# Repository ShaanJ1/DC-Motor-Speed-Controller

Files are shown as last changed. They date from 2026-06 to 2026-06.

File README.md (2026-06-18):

# DC-Motor-Speed-Controller
A PWM speed controller made for the 775 DC Motor, but can be used with other motors as well. It features on/off buttons, an indicator LED, and a potentiometer to control the motor's speed

I made this as Version 2 of my motor controller for my V8 Engine project, as that board failed to work entirely because of bad design.

# Bill of Materials (BOM)

| **Item Name/Purpose** | **Product Number** | **URL** | **Price** | **Quantity** | **Designator** | **Note** |
| --- | --- | --- | ---: | ---: | --- | --- |
| PCB | | https://jlcpcb.com/ | $3.50 | 5 | | |
| P Channel MOSFET | SI2323CDS-T1-BE3 | https://www.digikey.com/en/products/detail/vishay-siliconix/SI2323CDS-T1-BE3/16397482 | $1.21 | 1 | Q4 | |
| Zener Diode | MMSZ5V6T1G | https://www.digikey.ca/en/products/detail/onsemi/MMSZ5V6T1G/1749053 | $0.17 | 1 | D1 | |
| NPN Transistor | MMBT2222A-TP | https://www.digikey.ca/en/products/detail/mcc-micro-commercial-components/MMBT2222A-TP/717279 | $0.24 | 2 | Q3, Q6 | |
| 6A 2920 PTC Fuse | 2920L600/16MR | https://www.digikey.ca/en/products/detail/littelfuse-inc/2920L600-16MR/14320022 | $2.20 | 2 | F1 | |
| Flywheeling Diode | MBR2045CT | https://www.digikey.ca/en/products/detail/taiwan-semiconductor-corporation/MBR2045CT/7357796 | $1.72 | 1 | D3 | |
| N Channel MOSFET | IRF3205STRLPBF | https://www.digikey.ca/en/products/detail/infineon-technologies/IRF3205STRLPBF/856540 | $3.00 | 1 | Q5 | |
| Diode | 1N4148W-13-F | https://www.digikey.ca/en/products/detail/diodes-incorporated/1N4148W-13-F/1933928 | $0.36 | 2 | D5, D6 | |
| 0.01uF 0603 Capacitor | 06035C103MAZ2A | https://www.digikey.ca/en/products/detail/kyocera-avx/06035C103MAZ2A/11250083 | $0.12 | 1 | C2 | |
| 0.1uF 0704 C0G/NP0 Capacitor | GRMJN65C1H104JE01D | https://www.digikey.ca/en/products/detail/murata-electronics/GRMJN65C1H104JE01D/19115560 | $0.37 | 1 | C1 | |
| 555 Timer | LMC555 | https://www.digikey.ca/en/products/detail/texas-instruments/LMC555CMX-NOPB/334874 | $1.15 | 1 | U1 | |
| 10k 0603 Resistor | RC0603FR-0710KL | https://www.digikey.ca/en/products/detail/yageo/RC0603FR-0710KL/726880 | $0.25 | 10 | R1, R5, R6, R8, R11 | Cheaper to get 10 resistors than only 5 |
| 4.7K 0603 Resistor | RMCF0603FT4K70 | https://www.digikey.ca/en/products/detail/stackpole-electronics-inc/RMCF0603FT4K70/1760998 | $0.10 | 1 | R2 | |
| 1K 0603 Resistor | RMCF0603FT1K00 | https://www.digikey.ca/en/products/detail/stackpole-electronics-inc/RMCF0603FT1K00/1761077 | $0.21 | 10 | R3, R4, R7, R9, R10 | Cheaper to get 10 resistors than only 5 |
| 0805 SMD LED | LTST-C171KGKT | https://www.digikey.ca/en/products/detail/liteon/LTST-C171KGKT/386799 | $0.12 | 1 | D4 | |
| 1x2 Screw Terminals | 282837-2 | https://www.digikey.ca/en/products/detail/te-connectivity-amp-connectors/282837-2/2187973 | $3.44 | 2 | J1, M1 | |

#### <ins>Totals (not including taxes or shipping)</ins>

**Total (CAD):** $17.72

**Total (USD):** $12.57

### Images
Schematic


PCB




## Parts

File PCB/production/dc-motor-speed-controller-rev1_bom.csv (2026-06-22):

Designator | Footprint | Quantity | Value | LCSC Part #
C1 | GRMJN65C1H104JE01D | 1 | 100nF
C2 | 0603 | 1 | 0.01uF
D1 | D_SOD-123 | 1 | D_Zener
D3 | TO-220-3_Horizontal_TabDown | 1 | D
D4 | 0805 | 1 | LED
D5, D6 | Nexperia_CFP3_SOD-123W | 2 | D
F1 | 2920 | 1 | Fuse
J1 | TerminalBlock_Phoenix_MKDS-1,5-2-5.08_1x02_P5.08mm_Horizontal | 1 | Screw_Terminal_01x02
J10, J2, J3, J4, J5, J6, J7, J8, J9 | TestPoint_THTPad_2.0x2.0mm_Drill1.0mm | 9 | Conn_01x01
M1 | TerminalBlock_Phoenix_MKDS-1,5-2-5.08_1x02_P5.08mm_Horizontal | 1 | Motor_DC
Q2 | SOT-23 | 1 | NMOS
Q3, Q6 | SOT-23 | 2 | MMBT2222A
Q4 | SOT-23 | 1 | Si2319CDS
Q5 | TO-263-2 | 1 | NMOS
R1, R11, R5, R6, R8 | 0603 | 5 | 10K
R10, R3, R4, R7, R9 | 0603 | 5 | 1K
R2 | 0603 | 1 | 4.7K
U1 | SOIC-8_3.9x4.9mm_P1.27mm | 1 | LMC555xM

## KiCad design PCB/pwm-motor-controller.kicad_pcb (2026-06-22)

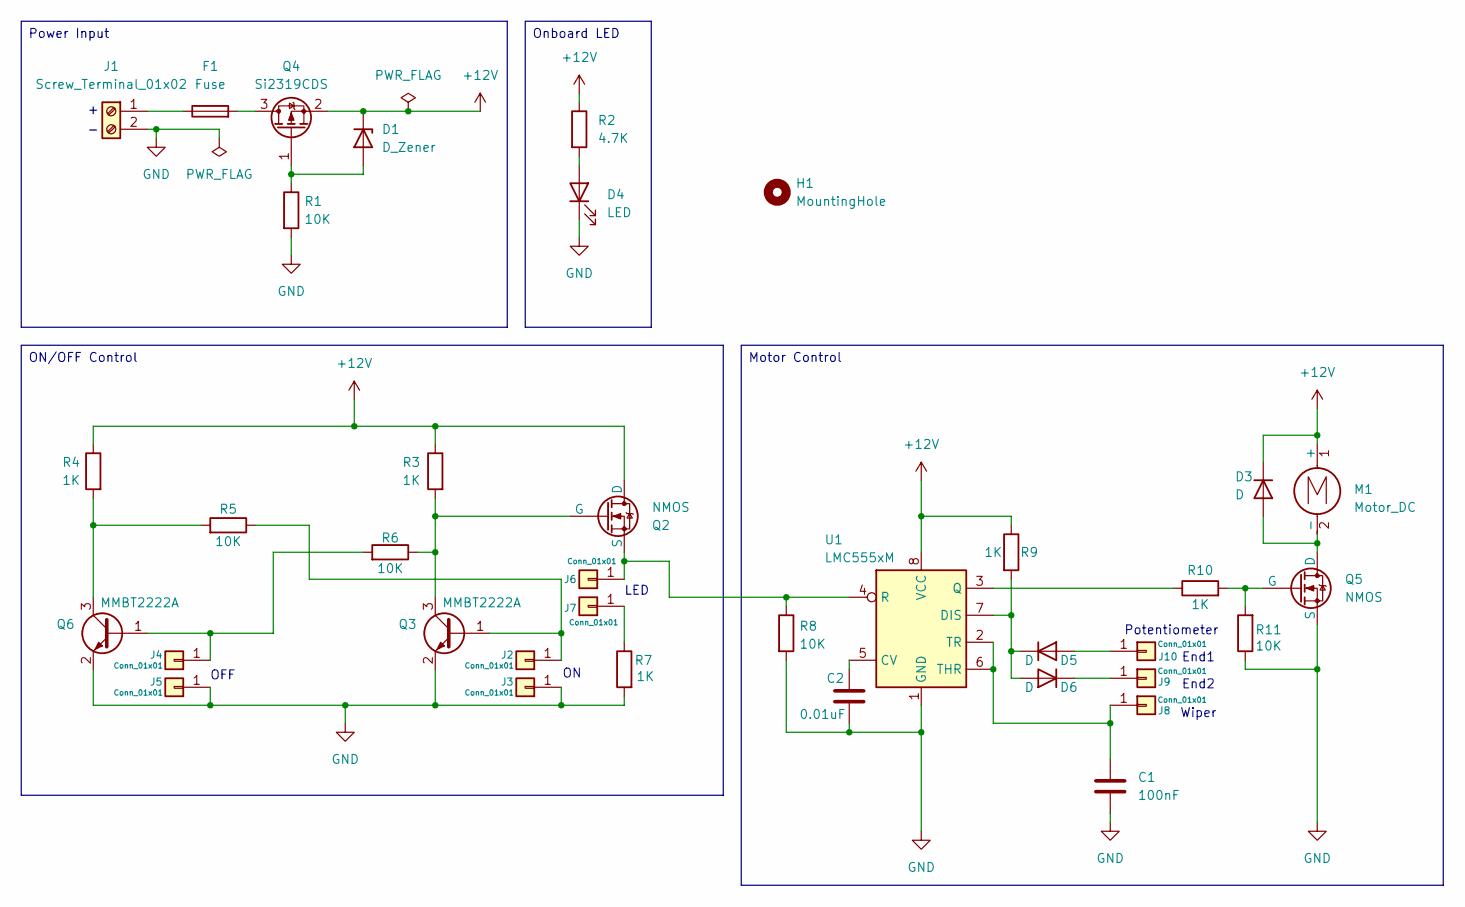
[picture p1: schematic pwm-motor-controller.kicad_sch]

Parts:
C1: 100nF; GRMJN65C1H104JE01D
C2: 0.01uF; C_0603_1608Metric
D1: D_Zener; D_SOD-123
D3: D; TO-220-3_Horizontal_TabDown
D4: LED; LED_0805_2012Metric_Pad1.15x1.40mm_HandSolder
D5, D6: D; Nexperia_CFP3_SOD-123W
F1: Fuse; Fuse_2920_7451Metric
H1: MountingHole; MountingHole_2.7mm_M2.5
J1: Screw_Terminal_01x02; TerminalBlock_Phoenix_MKDS-1,5-2-5.08_1x02_P5.08mm_Horizont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
J2, J3, J4, J5, J6, J7, J8, J9, J10: Conn_01x01; TestPoint_THTPad_2.0x2.0mm_Drill1.0mm
M1: Motor_DC; TerminalBlock_Phoenix_MKDS-1,5-2-5.08_1x02_P5.08mm_Horizont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
Q2: NMOS; SOT-23
Q3, Q6: MMBT2222A; SOT-23
Q4: Si2319CDS; SOT-23
Q5: NMOS; TO-263-2
R1, R5, R6, R8, R11: 10K; R_0603_1608Metric
R2: 4.7K; R_0603_1608Metric
R3, R4, R7, R9, R10: 1K; R_0603_1608Metric
U1: LMC555xM; SOIC-8_3.9x4.9mm_P1.27mm

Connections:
+12V: D1.1 (K), D3.1 (K), M1.1 (+), Q2.1 (D), Q4.2 (S), R2.1, R3.1, R4.1, R9.1, U1.8 (VCC)
GND: C1.2, C2.1, D4.1 (K), J1.2, J3.1, J5.1, Q3.2 (E), Q5.3 (S), Q6.2 (E), R1.2, R7.2, R8.2, R11.1, U1.1 (GND)
unnamed: D1.2 (A), Q4.1 (G), R1.1
unnamed: D3.2 (A), M1.2 (-), Q5.1 (D)
unnamed: D4.2 (A), R2.2
unnamed: D5.2 (A), J10.1
unnamed: D5.1 (K), D6.2 (A), R9.2, U1.7 (DIS)
unnamed: D6.1 (K), J9.1
unnamed: F1.1, J1.1
unnamed: J2.1, Q3.1 (B), R5.1
unnamed: J4.1, Q6.1 (B), R6.2
unnamed: J6.1, Q2.3 (S), R8.1, U1.4 (R)
unnamed: J7.1, R7.1
unnamed: C1.1, J8.1, U1.2 (TR), U1.6 (THR)
unnamed: Q2.2 (G), Q3.3 (C), R3.2, R6.1
unnamed: F1.2, Q4.3 (D)
unnamed: Q5.2 (G), R10.2, R11.2
unnamed: Q6.3 (C), R4.2, R5.2
unnamed: C2.2, U1.5 (CV)
unnamed: R10.1, U1.3 (Q)

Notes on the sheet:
LED
Potentiometer
Wiper
OFF
End2
End1
Power Input
ON/OFF Control
Onboard LED
Motor Control

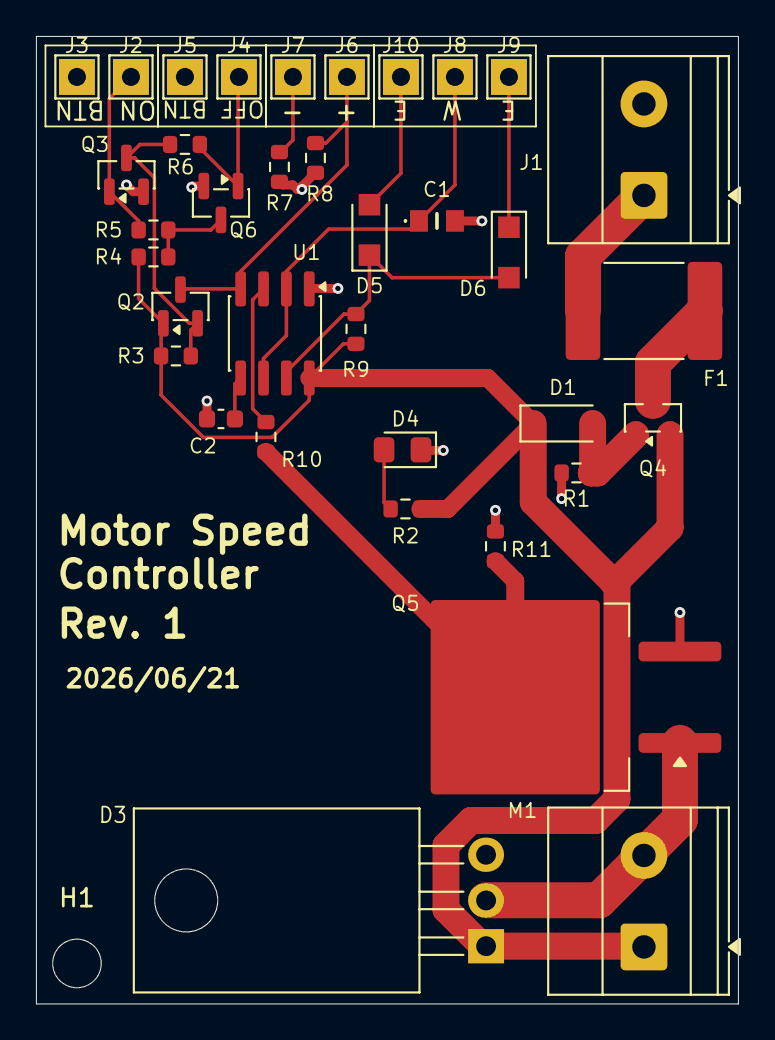
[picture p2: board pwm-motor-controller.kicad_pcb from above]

Board: 2 copper layers, 39.0 x 53.8 mm, 37 parts (0 on the bottom side), 20 nets.

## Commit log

2026-06-18 Update BOM
2026-06-22 Added mounting holes
    [bom.csv, dc-motor-speed-controller-rev1_bom.csv, dc-motor-speed-controller-rev1_designators.csv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]
2026-06-22 Remove duplicates
    [pwm-motor-controller.kicad_pcb]
